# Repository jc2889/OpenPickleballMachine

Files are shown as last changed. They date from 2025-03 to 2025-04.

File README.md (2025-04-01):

# OpenPickleballMachine



# Open-Source Pickleball Throwing Machine

This project presents a cost-effective, open-source pickleball throwing machine designed to bridge the gap between affordability and advanced features. It provides adjustable speed, spin control, and reliable ball feeding, allowing players to practice and improve independently. The open-source design encourages community collaboration, customization, and innovation, empowering users to enhance the machine to suit their specific needs.

## Features

- **Adjustable Speed:** Customize the speed of ball throws for a range of practice scenarios.
- **Spin Control:** Fine-tune the spin for more realistic training.
- **Reliable Ball Feeding:** Ensures consistent ball delivery for continuous practice.
- **Open-Source:** Full access to the design and code, allowing for easy modification and improvements.
- **Easy Maintenance:** Built using off-the-shelf parts, making repairs and upgrades simple.

## Requirements
`BOM.XLSX` for materials sourcing.

# Tools required for assembly: 
3D Printer (That can print ABS/ASA), impact driver, power drill, soldering iron, crimpers, wire strippers, hot glue gun, hex driver set, jigsaw.

# 3D printing specs:
We suggest using either ASA/ABS or better as a filament. Suggested standard 3 wall, 25% gyroid/cubic infil, 0.6mm nozzle.
Rollers should be printed with 95A TPU.
### Our specs: ASA-CF for filament
### Our Printers: Voron 2.4 350, Prusa MK4s, Bambu lab X1C
***We suggest using cast polyurethane rubber rollers instead of 3d printed TPU rollers as they work significantly better**

## Installation

### 1. Hardware Setup
- Assemble the machine using off-the-shelf components, including motors, motor controllers, and the Raspberry Pi.
- Follow the wiring instructions provided in the `docs/instructions` folder to connect the components.

### 2. Software Setup
- Download balena etcher: https://etcher.balena.io/
- Using balena etcher, flash the .img file in `docs/firmware` folder to download the needed firmware or follow the instructions on how to create your own.

### Recommended Software:

MobaXterm for SSH access on Pi
https://mobaxterm.mobatek.net/ 

CAD Software for editing printed parts or for modifications
Fusion 3D is free and easily usable, other recommendations are FreeCAD, Sketchup or Blender.

Slicer for 3d printing; Prusaslicer
https://www.prusa3d.com/page/prusaslicer_424/

# Connect the Pi to Wifi:
1. Open the SD card on your computer (it should be mounted as the boot partition), or connect the Pi via ethernet and SSH into it.
2. In the root directory, create a file named `wpa_supplicant.conf` and add the following content:

   ```txt
   country=CA
   ctrl_interface=DIR=/var/run/wpa_supplicant GROUP=netdev
   update_config=1
   network={
       ssid="YOUR_SSID"
       psk="YOUR_PASSWORD"
   }
   
## For further documentation and instructions:

Visit `docs/assembly`

### Clone the repository:
  ```bash
  git clone https://github.com/jc2889/OpenPickleballMachine.git
  cd OpenPickleballMachine

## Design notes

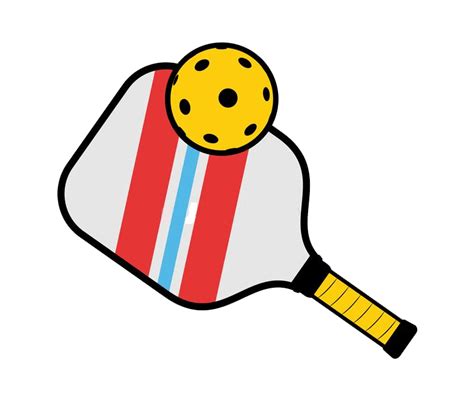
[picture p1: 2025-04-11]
docs/firmware/pickleball.jpeg

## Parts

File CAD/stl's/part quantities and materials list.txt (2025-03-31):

angle no slide.STL        - Qty: 2        - Material: ASA or PETG
angle slide.STL        - Qty: 2        - Material: ASA or PETG
ball disc.STL        - Qty: 1        - Material: ASA or PETG
ball_mover.STL        - Qty: 1        - Material: ASA or PETG
battery strap.STL        - Qty: 1        - Material: ASA or PETG
custom motor gear.STL         - Qty:2        - Material: ASA    (printed PETG example. please use the new STL file)
custom servo gear.STL        - Qty:1        - Material: ASA
custom wheel gear.STL        - Qty:2        - Material: ASA
electrical box.STL        - Qty:1        - Material: ASA or PETG
left mounting bracket.STL        - Qty:1        - Material: ASA or PETG
motor bracket.STL        - Qty:2        - Material: ASA
right mounting bracket.STL        - Qty:1        - Material: ASA or PETG
ring gear.STL        - Qty:1        - Material: ASA
roller frame.STL        - Qty:1        - Material: ASA
screen mount.STL        - Qty:1        - Material: ASA or PETG
TPU launcher wheel.STL        - Qty:1        - Material: TPU    (already printed)
tube.STL        - Qty:1        - Material: ASA or PETG

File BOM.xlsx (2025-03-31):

Date | Vendor | Item | Price (CAD) | GST (5%) | PST (7%) | Total (CAD) | Purchaced | link
2024-12-24 | Lee's Electronics | Sewable Neopixel WS2812 LED 5050 RGB x 2 | 8 | 0.4 | 0.56 | 8.96 | TRUE
2024-12-25 | Lee's Electronics | IEC Socket w/ Rocker Switch and Fuse Holder | 5.5 | 0.28 | 0.39 | 6.17 | TRUE
2024-12-26 | Lee's Electronics | Raspberry Pi 4 Model B, 4GB RAM | 97.5 | 4.88 | 6.83 | 109.21 | TRUE
2024-12-27 | Lee's Electronics | IEC Power Cord AWG18X3C 10FT | 6.8 | 0.34 | 0.48 | 7.62 | TRUE
2024-12-27 | Best Buy | Lexar 633X MicroSD 128GB | 13.99 | 0.7 | 0.98 | 15.67 | TRUE
 |  |  |  |  |  |  | FALSE
 |  |  |  |  |  |  | FALSE
2025- 02- 14 | home depot | battery | 34.77 | 1.7385 | 2.4339 | 38.9424 | TRUE | https://www.homedepot.ca/product/mighty-max-battery-ml9-12-12-volt-9-ah-f2-terminal-rechargeable-sla-agm-battery/1001859228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
 |  | battery charger | 20.13 | 1.0065 | 1.4091 | 22.5456 | FALSE | https://www.homedepot.ca/product/mighty-max-battery-12-volt-2-amp-sla-battery-charger-and-maintainer/1001860316
2025- 01-17 | Amazon | 2 driver motors | 47 | 2.35 | 3.29 | 52.64 | TRUE | https://a.co/d/i0Xx5XO
2025- 01-17 | Amazon | 2 dual driver escs | 30.22 | 1.511 | 2.1154 | 33.8464 | TRUE | https://www.amazon.ca/Channel-Controller-Semiconductor-Automotive-Electronics/dp/B07BKPV5Z7
2025- 02- 14 | aliexpress | 1 feeder motor (continuous servo) | 9.08 | 0.454 | 0.6356 | 10.1696 | TRUE | https://www.aliexpress.com/item/1005006777637870.html?pdp_ext_f=%7B%22order%22%3A%221%22%7D (https://www.aliexpress.com/item/1005008290985117.html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)
 |  | 2020 extrusion | 69.24 | 3.462 | 4.8468 | 77.5488 | FALSE | https://www.aliexpress.com/item/1005004263746376.html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
2025- 02- 14 | aliexpress | fasteners (M4 assorted length) | 10 | 0.5 | 0.7 | 11.2 | TRUE | https://www.aliexpress.com/item/1005004527586307.html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
2025- 02- 14 | aliexpress | m4 nuts |  | 0 | 0 | 0 | TRUE
 |  | 4 feeder wheels (maybe only 2, depending on budget) (could print TPU) | 21.98 | 1.099 | 1.5386 | 24.6176 | FALSE
2025- 01-17 | Amazon | voltage step down module | 12.59 | 0.6295 | 0.8813 | 14.1008 | TRUE | https://www.amazon.ca/LM2596S-Power-Module-DC-DC-Step-Down/dp/B0CXXP7RHP
2025- 01-18 | Home Depot | high current wires | 5.2 | 0.26 | 0.364 | 5.824 | TRUE | home depot
 |  | T Nuts (M4) | 5.93 | 0.2965 | 0.4151 | 6.6416 | FALSE | https://www.aliexpress.com/item/33023772052.html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
 |  | Couple Gallon Pale | 4.77 | 0.2385 | 0.3339 | 5.3424 | FALSE | https://www.homedepot.ca/product/the-home-depot-19l-orange-home-depot-logo-plastic-paint-bucket/1000143871
2025- 02- 14 | amazon | Bearings | 11.49 | 0.5745 | 0.8043 | 12.8688 | TRUE | https://www.amazon.ca/uxcell-4-inchx3-8-inchx1-Shielded-Bearings/dp/B0828JXX4N
2025- 02- 14 | aliexpress | servo driver board | 4.46 | 0.223 | 0.3122 | 4.9952 | TRUE | https://www.aliexpress.com/item/1005006298833960.html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
 |  | high torque servos x2 | 27.32 | 1.366 | 1.9124 | 30.5984 | FALSE | https://www.aliexpress.com/item/1005007792248497.html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
2025- 02- 14 | aliexpress | continuous servo | 9.08 | 0.454 | 0.6356 | 10.1696 | TRUE | https://www.aliexpress.com/item/1005006777637870.html?pdp_ext_f=%7B%22order%22%3A%221%22%7D (https://www.aliexpress.com/item/1005008290985117.html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)
 |  | cooling fan | 8.02 | 0.401 | 0.5614 | 8.9824 | FALSE | https://www.aliexpress.com/item/1005003140484906.html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
2025- 02-03 | Amazon | dupont wires | 8.99 | 0.4495 | 0.6293 | 10.0688 | TRUE | https://www.aliexpress.com/item/1005002599108827.html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
2025- 02-03 | Amazon | breadboard | 9.99 | 0.4995 | 0.6993 | 11.1888 | TRUE | https://www.aliexpress.com/item/1005004532352681.html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
 |  | 12 socket | 3.85 | 0.1925 | 0.2695 | 4.312 | FALSE | https://www.aliexpress.com/item/1005005827656117.html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
 |  | lipo | 89.97 | 4.4985 | 6.2979 | 100.7664 | FALSE
2025- 02-02 | Amazon | connectors | 10.99 | 0.5495 | 0.7693 | 12.3088 | TRUE
 |  | wood screws
 |  |  |  |  | Optional features | Total (CAD): | 657.3084
Spent in the display
Where | $ | Included in purchase
Lee's electronics | 131.94 | neopixels, pi, iec cord and socket
best buy | 15.67 | micro sd
amazon | 95.49 | 2 escs, 2 motors, 12v-5v step down modules
amazon | 10.07 | dupont wires
amazon | 25.74 | pi prototype board, pin header kit
home depot | 5.74 | 12 gauge wires
home depot | 38.94 | battery
aliexpress | 28.31 | continuous servos, servo controler, m4 hardware
amazon | 12.87 | bearings
home depot | 49.77 | 2 8ft boards, wood screws(1in and 3in), hinges, bucket, axle bolts + nuts, m4 washers
Home Depot | 20.68 | Wagos, wire, spade connectors.
amazon | 48.99 | screen
total spent | 484.21
remaining | 15.79

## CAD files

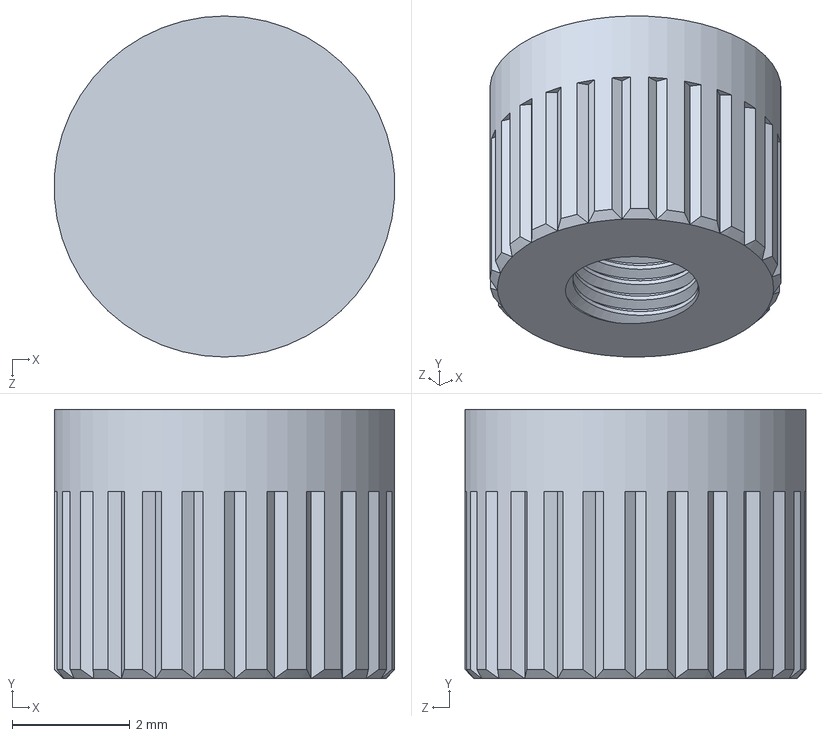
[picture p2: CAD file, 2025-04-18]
CAD/SOLIDWORKS/Shaft.SLDPRT
5.79 x 4.58 x 5.80 mm

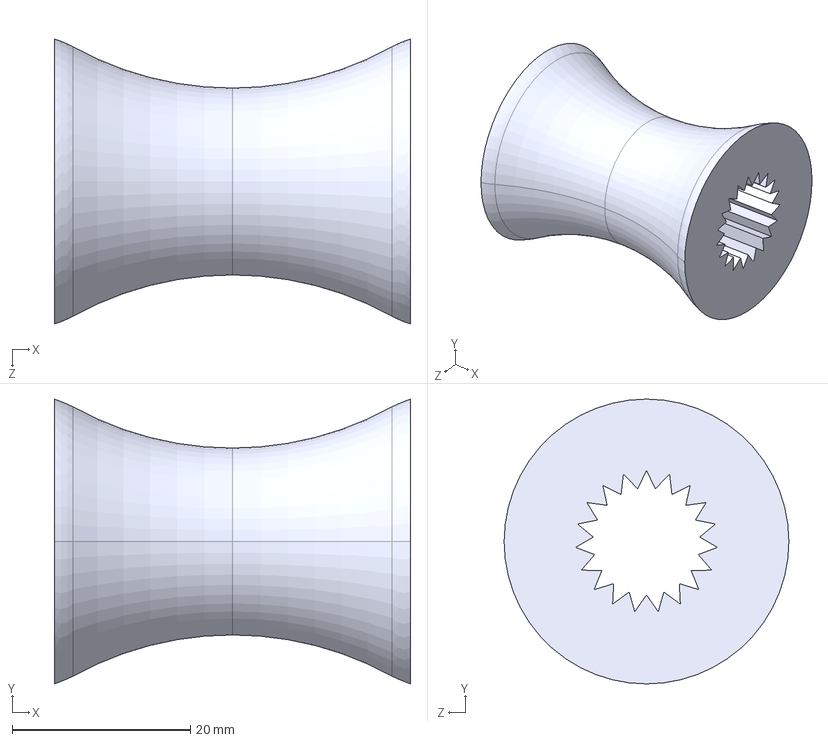
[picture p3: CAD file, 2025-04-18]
CAD/STEP files/TPU launcher wheel undersize.STEP
40.0 x 32.0 x 32.0 mm

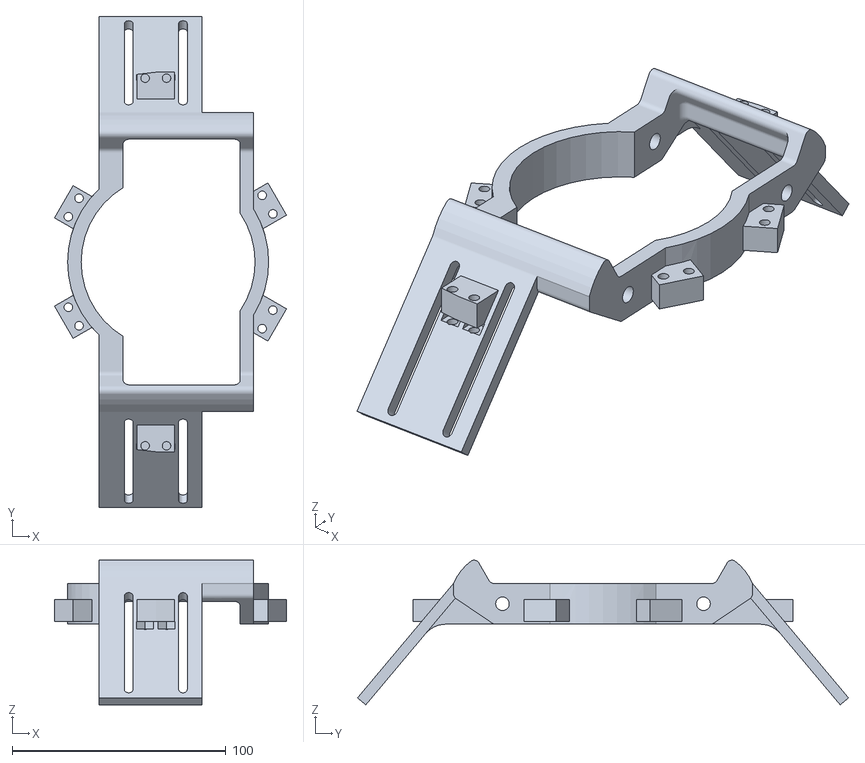
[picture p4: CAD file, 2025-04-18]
CAD/stl's/roller frame.STL
108.5 x 229.5 x 67.6

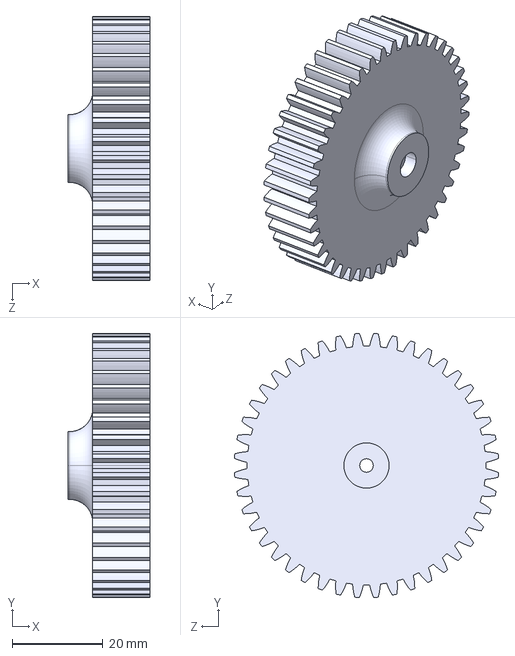
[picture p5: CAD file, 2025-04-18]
CAD/STEP files/custom servo gear.STEP
18.2 x 58.3 x 58.3 mm

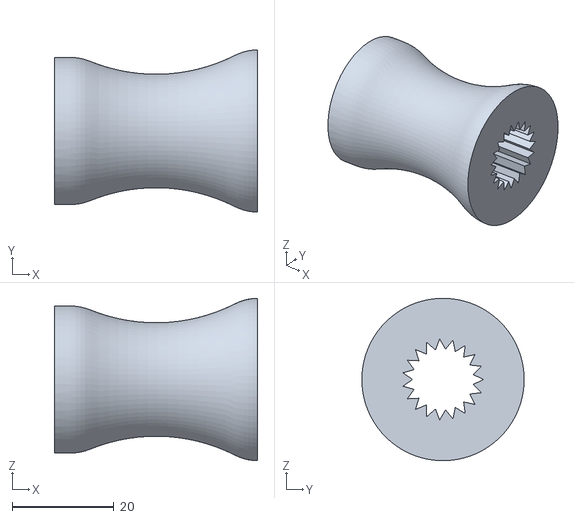
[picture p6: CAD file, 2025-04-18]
CAD/stl's/TPU launcher wheel 2%.STL
40.0 x 32.0 x 32.0

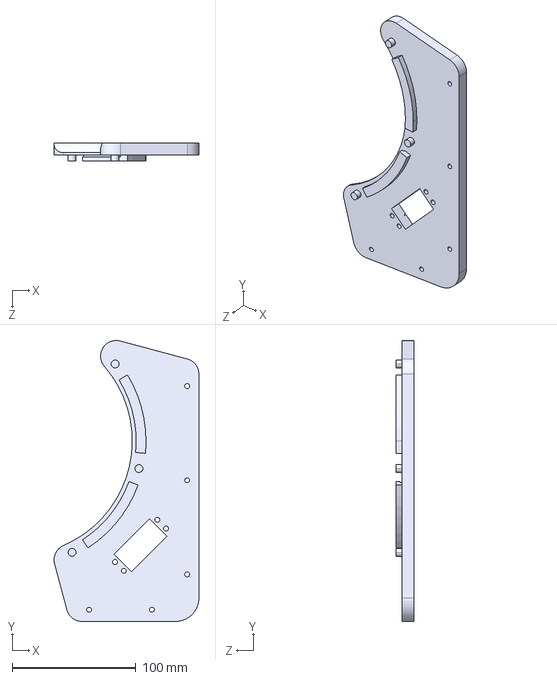
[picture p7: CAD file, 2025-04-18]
CAD/STEP files/right mounting bracket.STEP
117.2 x 227.4 x 14.3 mm

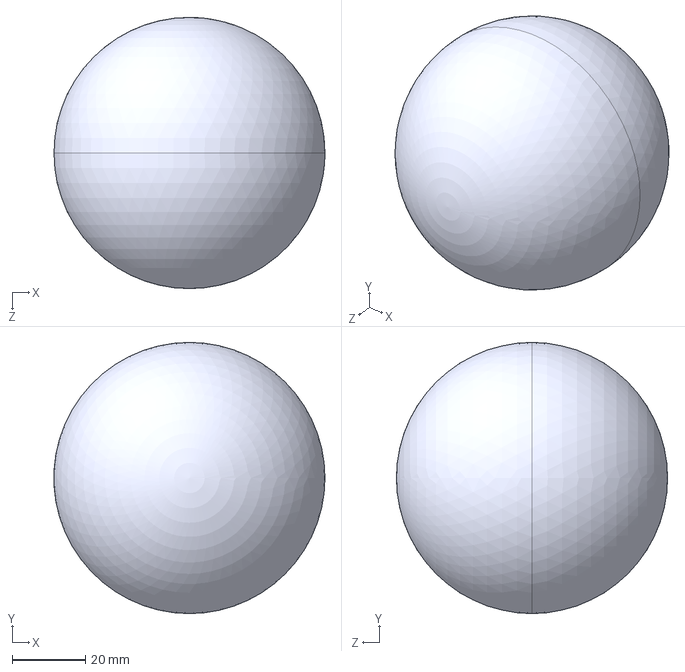
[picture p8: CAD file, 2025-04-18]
CAD/STEP files/pickleball.STEP
73.9 x 74.0 x 74.0 mm

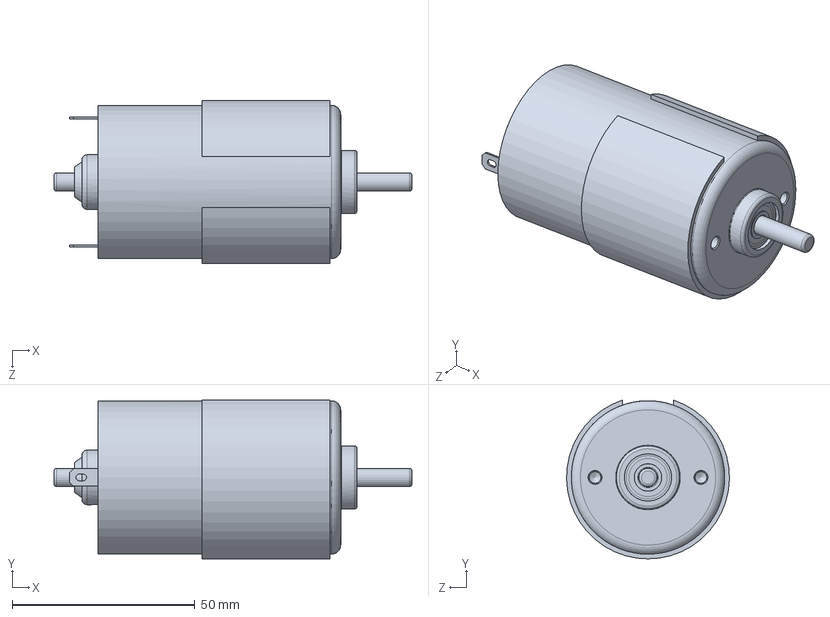
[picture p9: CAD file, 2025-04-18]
CAD/SOLIDWORKS/Motor - RS-775 simplified.SLDPRT
98.0 x 43.5 x 44.6 mm

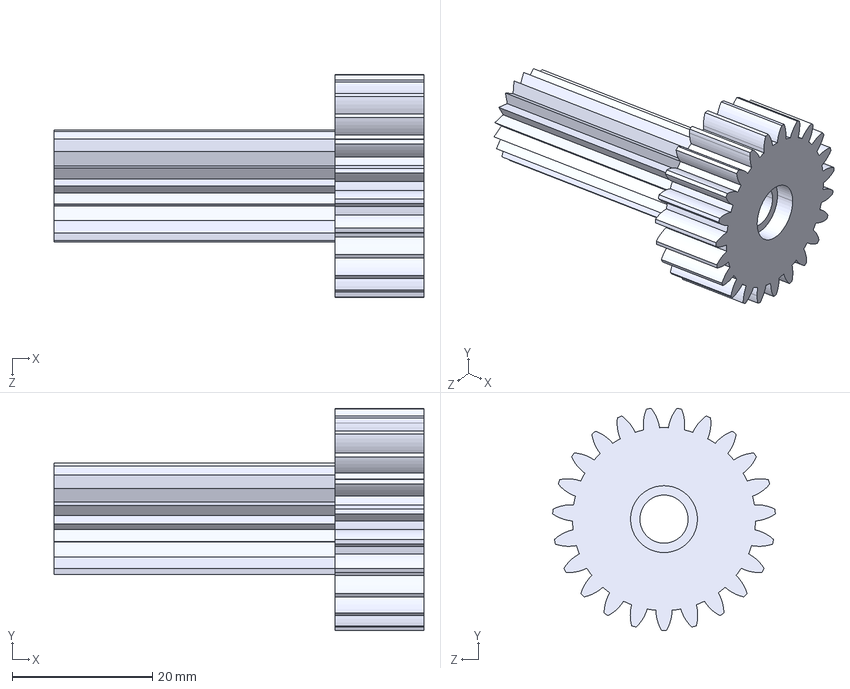
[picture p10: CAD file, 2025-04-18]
CAD/STEP files/custom wheel gear.STEP
52.7 x 31.6 x 31.7 mm

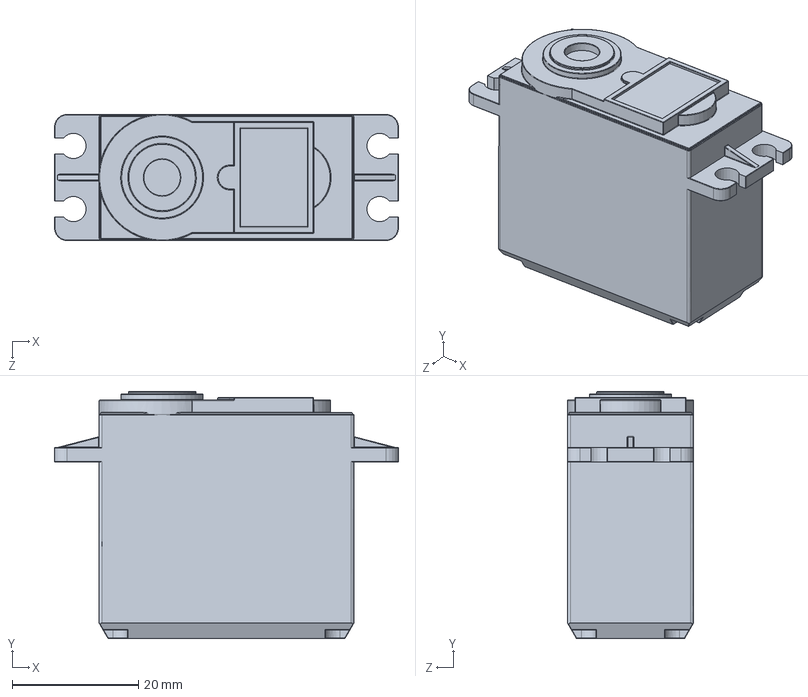
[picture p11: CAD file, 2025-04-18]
CAD/SOLIDWORKS/MG995.SLDPRT
54.5 x 39.2 x 20.0 mm

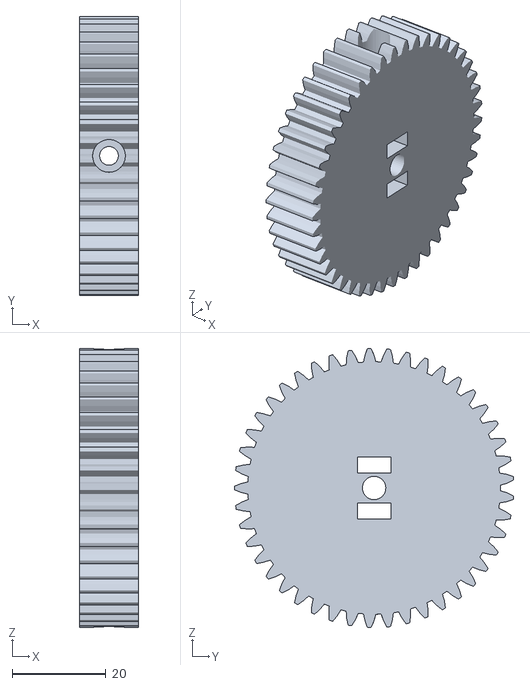
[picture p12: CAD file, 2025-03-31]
CAD/stl's/custom motor gear.STL
12.7 x 59.6 x 59.7

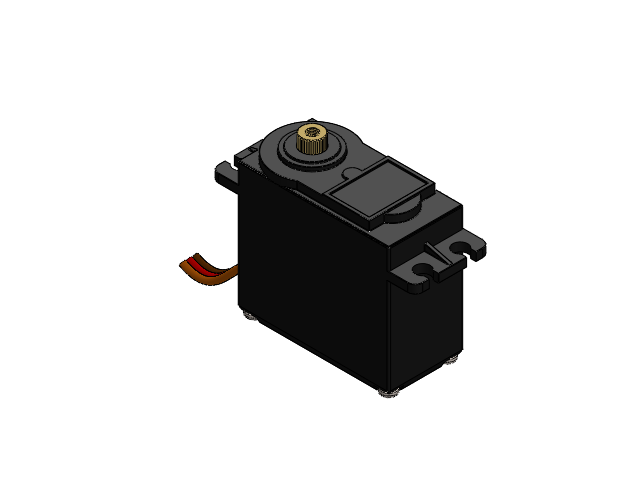
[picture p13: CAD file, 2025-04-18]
CAD/SOLIDWORKS/MG995 Assembly.SLDASM
MG995
Shaft
Wire Boot
Wires
pan head tapping screw_am x 4

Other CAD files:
CAD/SOLIDWORKS/Wire Boot.SLDPRT
CAD/stl's/TPU launcher wheel.STL
CAD/SOLIDWORKS/Wires.SLDPRT
CAD/stl's/TPU launcher wheel 1%.STL
CAD/stl's/TPU launcher wheel 5%.STL
CAD/STEP files/left mounting bracket.STEP
CAD/SOLIDWORKS/2x3 wood.SLDPRT
CAD/SOLIDWORKS/57155K375_Stainless Steel Ball Bearing.SLDPRT
CAD/SOLIDWORKS/TPU launcher wheel.SLDPRT
CAD/SOLIDWORKS/angle no slide.SLDPRT
CAD/SOLIDWORKS/angle slide.SLDPRT
CAD/SOLIDWORKS/ball disc.SLDPRT
CAD/SOLIDWORKS/ball_mover.SLDPRT
CAD/SOLIDWORKS/battery strap.SLDPRT
CAD/SOLIDWORKS/battery.SLDPRT
CAD/SOLIDWORKS/bucket.SLDPRT
CAD/SOLIDWORKS/custom motor gear.SLDPRT
CAD/SOLIDWORKS/custom servo gear.SLDPRT
CAD/SOLIDWORKS/custom wheel gear.SLDPRT
CAD/SOLIDWORKS/electrical box.SLDPRT
CAD/SOLIDWORKS/feed.SLDASM
CAD/SOLIDWORKS/left mounting bracket.SLDPRT
CAD/SOLIDWORKS/motor bracket.SLDPRT
CAD/SOLIDWORKS/pickleball.SLDPRT
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

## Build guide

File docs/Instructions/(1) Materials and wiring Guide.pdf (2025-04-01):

Appendix B: Open-Source and Assembly Instructions

B.1 Materials List

Below is a comprehensive list of all components required to replicate the pickleball throwing machine. All parts were selected based on affordability, availability, and DIY-friendliness. Suggested quantities and models are included. Links to product pages should be added by the user.

Electronics & Control

- 1× Raspberry Pi 4 Model B (2GB or higher)
Used for system control and user interface
[Link: https://www.raspberrypi.com/products/raspberry-pi-4-model-b/ ]
- 1× Micro SD Card (16GB or higher)
Used to boot and store the Raspberry Pi OS and project files
[Link:
https://www.bestbuy.ca/en-ca/product/sandisk-ultra-32gb-100mb-s-micro-sd-card-sdsquns-032g/13695879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]
- 1× Touchscreen Display (HDMI + USB input)
Used for real-time user control and configuration
[Link: https://www.amazon.ca/dp/B0CRRB1GFN?ref=ppx_yo2ov_dt_b_fed_asin_title]
- 1× LM2596S-5 Step-Down Voltage Regulator (12V to 5V)
Powers the Raspberry Pi from the main battery source
[Link:
https://www.amazon.ca/LM2596S-Power-Module-DC-DC-Step-Down/dp/B0CXXP7RHP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

UEfcUG44k5tJmPM3_J5_e1sBA_XIdUGrHoy6O_dAi2qjwUb-T0oHOcF3PnMQ1Fbg6r xxjV_53fNjoton0Xw2flCZ0HFcfvkkV4ATEcKNaDElkPZLy1HC2ggzfiFFqW-Wuaou6i VbMOvFhtdLrhzn24Iu5p8BXH8brrUAQH5xhcgiR5VlnAJRgs0amjl5_XgnRwlNp2qFN HwF-DhspwvmSVJvMDXM-oN_leD7jP86jVoSHVq1IfZ5wOAe8mCK0iO3JjLW1x_53 9MTUuLQy3wqc1NwYH2haOptJFfr_3Fhiy6Fi46hQq2HwQak2tl5K6-F_tm_RPEVEFzc ZeDDBXCPSmZ0Qq0DqK-jIWgWqdBzE7lKTOcrpseL89hBiCYbnfYnxfhwVLos2N_u psiK6GmBS8fbpXS2R-uT8C3D.5NMLD2pXluSVnKJdG1vdfo3LKvzGY6NUs-Yc04AmDs&dib_tag=se&keywords=12v+to+5v&qid=1737091439&sprefix=12v+to+5v%2Cap s%2C176&sr=8-13]

- 1× PCA9685 16-Channel PWM Servo Driver
Controls both continuous rotation servos
[Link:
https://www.aliexpress.com/item/1005006298833960.html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 2.99%21%21%2122.20%2114.88%21%402101ea8c17371818965312061e904d%211200 0037529842018%21sea%21CA%210%21ABX&curPageLogUid=4X131uRG9vee&utpa ram-url=scene%3Asearch%7Cquery_from%3A]
- 1× 12V 9Ah Sealed Lead-Acid (SLA) Battery (Mighty Max ML9-12 or equivalent) Main power source for motors and electronics
[Link:
https://www.homedepot.ca/product/mighty-max-battery-ml9-12-12-volt-9-ah-f2-terminal-rechargeable-sla-agm-battery/1001859228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]

Motors & Actuation

- 2× 775 DC Motors (12V, 0.32A, ~13000 RPM)
Used to drive the launching wheels
[Link:
https://www.amazon.ca/dp/B0C1CPVVTF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]
- 2× Continuous Rotation Servo Motors (DS04-NFC or equivalent)
Used for the feeding and launch angle adjustment mechanisms
[Link:
https://www.aliexpress.com/item/1005008290985117.html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 17.99%21%21%215.42%215.42%21%402101d9ee17371786323311474e7289%2112000 044500754039%21sea%21CA%210%21ABX&curPageLogUid=Bqh9kpQDENj1&utpar am-url=scene%3Asearch%7Cquery_from%3A]
- 2× Single-Channel H-Bridge Motor Driver Boards (LM2936 or equivalent)
Drives each DC motor independently
[Link:
https://www.amazon.ca/Channel-Controller-Semiconductor-Automotive-Electronics/dp/B07BKPV5Z7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 nd_I_gst6TK-PtAlmoOAyVeUgy72iNZ8jGLESIwvJhgZofWLVTq-59tQ.NiJSd1uO-fCIn A9ndMZXKSzmSezdCYtIfWHHJfYA8nI&dib_tag=se&keywords=Cytron&qid=173708 9191&sprefix=cytron%2Caps%2C133&sr=8-9]

Connectors & Wiring

- 1× Pi Prototype Board or Breadboard Kit
Optional, for initial testing or soldered connections
[Link: https://52pi.com/products/52pi-prototype-hat-breadboard-for-raspberry-pi]
- 1× IEC Power Connector and Socket
Used for battery charging or external supply integration
[Link:
https://leeselectronic.com/en/product/21069-rocker-switch-w-iec-socket-fuse-holder-scre w.html]
- Assorted Wires (Dupont jumper wires, 12-gauge power wire)
Used for general wiring and power distribution
[Link:
https://www.aliexpress.com/item/1005002599108827.html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 1.51%21%21%211.53%211.03%21%402101c72a17371787415886971e5288%21120000 21331960075%21sea%21CA%210%21ABX&curPageLogUid=5epYVaPxuz0v&utpara m-url=scene%3Asearch%7Cquery_from%3A]
- Wago Connectors / Spade Connectors / Crimp Connectors
Used for secure and modular electrical connections
[Link:
https://www.wago.com/us/wire-splicing-connectors/compact-splicing-connector/p/221-41 5

https://www.amazon.ca/Feggizuli-Connectors-Connector-Terminals-Electrical/dp/B0B4H54KPS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

Y373MlpljQ9zPu-LacliQaF39fZeV0qy6bNfHnF6yWLbiUenfBHIx9XyQ1AL73CVxRG nCx4ViPi1PsrHIaxYomVC1huoSW3w68LiIhB92PaaS9dyNqZ-T6hOQ5OmxSmn7ZPFx wzBjch5a2xmrfxqoQRawVI_1fXR0JRG6zMQYGY_Moy_Bo5onXIK2jXxIToPGEzzyR JmuDMHwP61LeLEHjvlTD2ONXqf7h0f6rD89CmdRs_y0MLoSyWjPZOsF7K5JTbLR bOq5-R1i2peszIHY4XDFRbTHvxA89KO.FW5X3_TQc9tTwtC4Ou_upmIkmzB4S1Yf9 0mqSlbb-wU&dib_tag=se&keywords=crimp%2Bconnectors&qid=1742840991&sprefix =crimp%2Bconn%2Caps%2C166&sr=8-5&th=1

]

Mechanical Components

- Ball Bearings
Used in rotating or tensioned mechanisms (e.g., launcher wheel support)
[Link:
https://www.amazon.ca/uxcell-4-inchx3-8-inchx1-Shielded-Bearings/dp/B0828JXX4N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 JA0odIiIrXa23jwhvvUkC6XhbRQbEkHLWW4aVSqbcJ-1Y5R0fIdq7NMTvEclMCSJS DTkXp-NO7ihhKi7ocJxLhDykAkWBJu8sXgKtQieVuz6eOibPwWEZuAdzsjlqHSZOhs 8nxDZWPw3O_nTudCbqRS32JfDAZ3VgffWXdLzzN9frLyi1UbHw7j3oU07YROJ6zka QrvMHsMKraH73GqhuZsKnmoGvA1HQ0HNL_d-VbIYoonpJrk5fKrcpjC6f-PYqBdqU 2l26MgjidUoKc_FDIrM0csy.SX76jApIdP0uKtFNR7KGz4ll7OHpeIGds-Eaol1bF00&di b_tag=se&keywords=r168+bearings&qid=1738465099&sprefix=r168+bearings%2Caps %2C156&sr=8-5]
- M4 Hardware (Nuts, Bolts, Washers, Axle Bolts)
Used for mounting and assembly of 3D printed and mechanical components [Link:

https://www.amazon.ca/uxcell-4-inchx3-8-inchx1-Shielded-Bearings/dp/B0828JXX4N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 JA0odIiIrXa23jwhvvUkC6XhbRQbEkHLWW4aVSqbcJ-1Y5R0fIdq7NMTvEclMCSJS DTkXp-NO7ihhKi7ocJxLhDykAkWBJu8sXgKtQieVuz6eOibPwWEZuAdzsjlqHSZOhs 8nxDZWPw3O_nTudCbqRS32JfDAZ3VgffWXdLzzN9frLyi1UbHw7j3oU07YROJ6zka QrvMHsMKraH73GqhuZsKnmoGvA1HQ0HNL_d-VbIYoonpJrk5fKrcpjC6f-PYqBdqU 2l26MgjidUoKc_FDIrM0csy.SX76jApIdP0uKtFNR7KGz4ll7OHpeIGds-Eaol1bF00&di b_tag=se&keywords=r168+bearings&qid=1738465099&sprefix=r168+bearings%2Caps %2C156&sr=8-5]

3D Printing Materials

- ASA Filament
Used for UV-resistant structural parts (e.g., housing, brackets, gear mounts)
[Link:
https://www.amazon.ca/OVERTURE-Filament-Printing-Functional-Dimensional/dp/B0CPXJ5RT5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 nYhMUHoh42gcPcDPtNrK8LWNEGwSeBvwujehLXBeuuoIzAaOHktBm6yJQtjcNTSo ic8xHXADM2VMjD_qMwBSrLBBi7zRUsGRB-Tz6GOYY41B9lzSnhXQRBD3hfNbm o4QpjYdYghtJ9GUcDclWFzBKRjnOenCm96hHoBPCW8JczFjgbiZQzmIzm3-wgDIRo nozKl2Jz4l_1L1LeDvdSP9dXaxpA5lgmM5mpZWMabjfJh5DLj_j8nRhidufNIL1fjajimS lIMT5cLNcJs--xILtIuNxDWstNrf0uH5T.2du9scbxr5CsAZkDjtP-O_YdQ9Zhw9_OqF90 2w9sM5c&dib_tag=se&keywords=asa+filament&qid=1742841067&sprefix=ASA+%2C aps%2C149&sr=8-5]

- TPU Filament
Used for the launcher wheels for improved grip and durability
[Link:
https://www.amazon.ca/Overture-Filament-Flexible-Consumables-Dimensional/dp/B0841CKM6F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 Hvf0JEu7HP7U2q5govOFFEiop0jMCJF7f5X0Vb3NjRivQOP9Z6Z5bPU2YcbK7JQZm HZmbNwMq_mOobjK48ZvcvwtWD6ROXQ-zXxAtpW0fYZYjGwAcfO5hKnFCKZBS Oi2-kDT7fdJsfFm0CiepwvwyTkA7qpKPfOFI6m9vUVBJcTGlsLISVCLdDRup9SCTIpI 8932ixUVRU-bW_Q.qmH6Ia461wtSs05FTvUrReXaVvYWkNlcH1Hd2mCed98&dib_t ag=se&keywords=tpu+filament&qid=1742841080&sprefix=tpu+filament%2Caps%2C17 7&sr=8-5]

Frame Materials

- 2× 8-ft Wooden Boards
Used for the base and support structure
[Link:
https://www.homedepot.com/p/2-in-x-3-in-x-8-ft-2-Select-Grade-Dimensional-Lumber-845000/100038668]
- Wood Screws (1” and 3”)
General assembly of frame and component mounting
[Link:
https://www.homedepot.ca/product/kreg-tool-company--8-1-1-4-inch-square-maxi-loc-head-coarse-zinc-plated-steel-pocket-hole-screw-100-pack-/1000711142]
- Hinges, Bucket, and Additional Support Brackets (as required)
Used for ball loading and launch positioning mechanisms

[Link:
https://www.homedepot.ca/product/the-home-depot-19l-orange-home-depot-logo-plasticpaint-bucket/1000143871

https://www.homedepot.ca/product/richelieu--2-pack-non-mortise-bifold-inset-hinge-forframed-cabinet-matte-black/1001066169]

B.2 Electrical Connections

This section provides an overview of the electrical wiring required to operate the pickleball throwing machine. The system is powered by a 12V sealed lead-acid battery, stepped down via a voltage regulator to supply safe and consistent power to the Raspberry Pi 4B, motors, and servo controller.

A complete circuit schematic is provided below for reference, along with supporting images of the prototype wiring.

B.2.1 System Overview

- Power Source:
A 12V 9Ah SLA battery powers the entire system. The Raspberry Pi is powered via a LM2596 step-down converter that outputs 5V.
- Motor Drivers:
Two DC motors are controlled using single-channel H-bridge drivers (LM2936). Each motor is wired to a separate GPIO pair on the Raspberry Pi for directional control.
- Servo Controller:
A PCA9685 PWM driver board is connected via I2C to control two continuous rotation servo motors (for feeding and launch angle adjustment).
- Display Power:
The touchscreen display connects via micro HDMI and USB, and is powered via the Raspberry Pi. (In earlier iterations, powering the display directly caused instability, which was resolved by powering the Pi through the LM2596 converter.)

B.2.2 Circuit Schematic

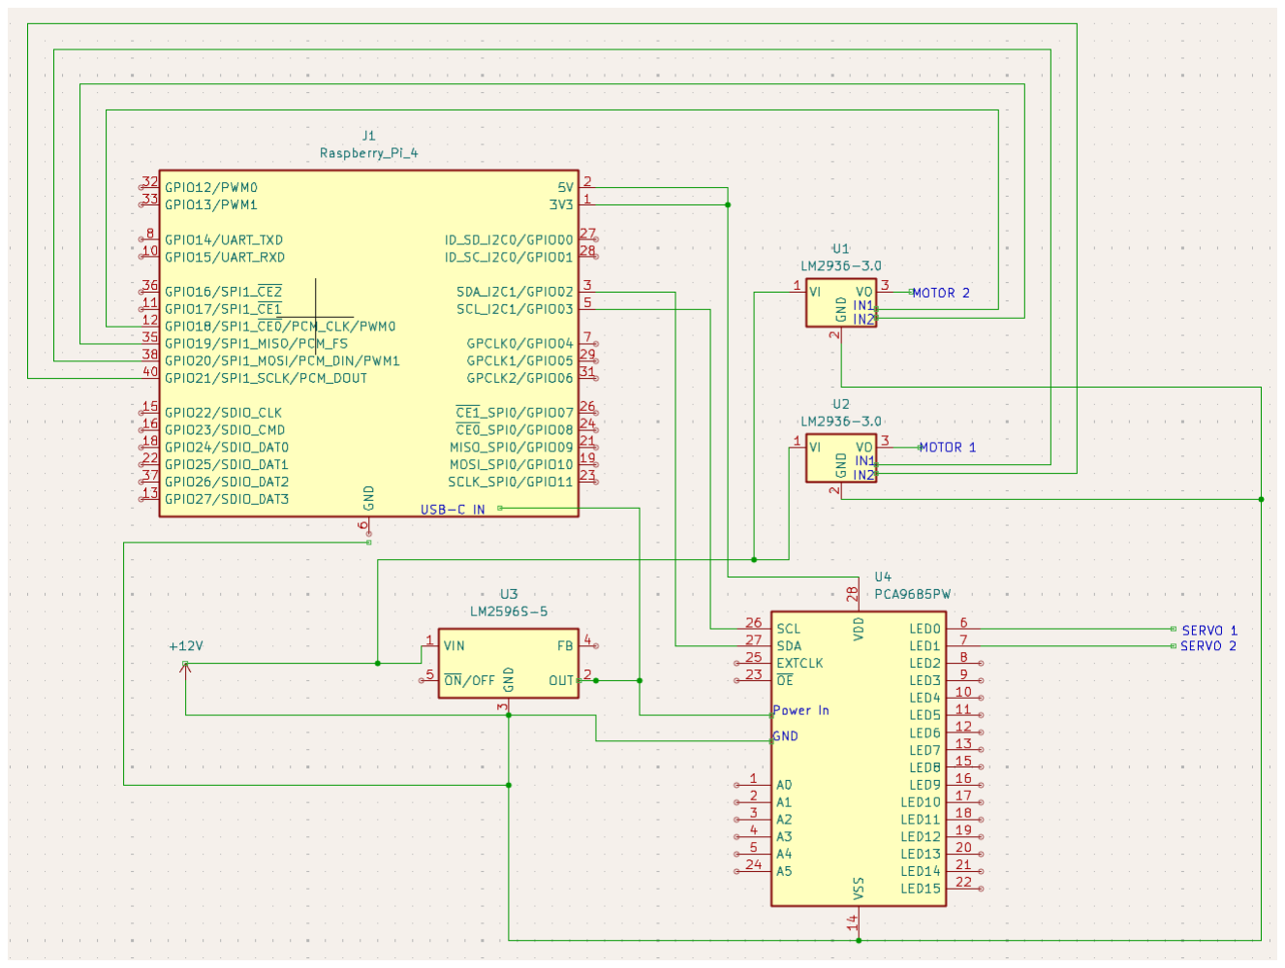
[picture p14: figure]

Figure B.1 – Full Circuit Schematic for Pickleball Throwing Machine

B.2.3 Wiring Images

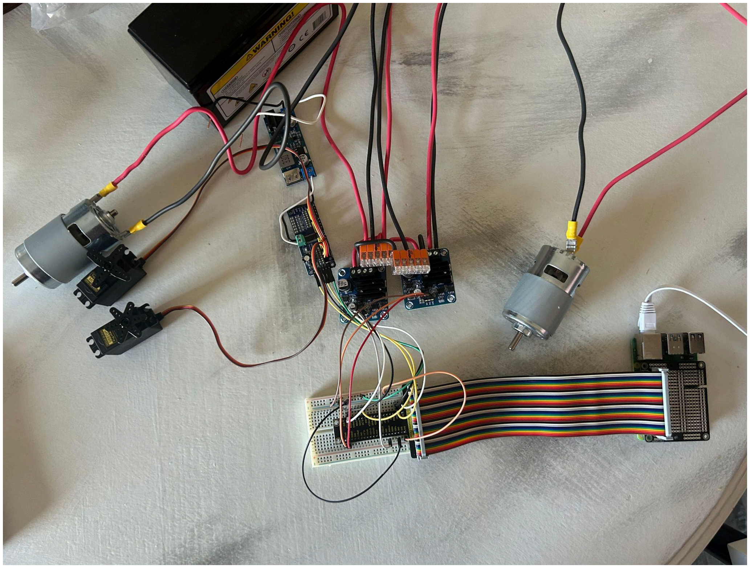
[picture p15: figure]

Figure B.2 – Assembled Wiring Example

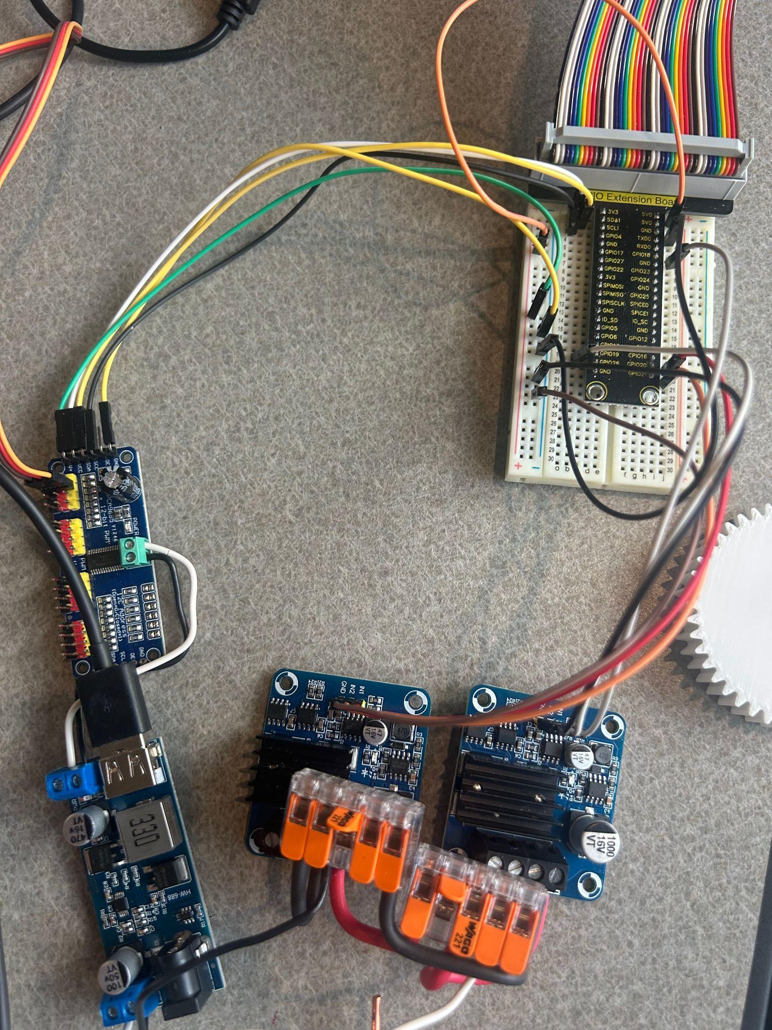
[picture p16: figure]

Figure B.3 – Close-up of Motor Driver Wiring and Power Distribution

B.2.4 GPIO and I2C Pin Mapping (Raspberry Pi)

Function | Raspberry Pi Pin | Connection
Servo I2C – SDA | GPIO 2 (Pin 3) | PCA9685 SDA
Servo I2C – SCL | GPIO 3 (Pin 5) | PCA9685 SCL
Motor 1 IN1 / IN2 | GPIO 18 / GPIO 19 | LM2936 (Motor 1)
Motor 2 IN1 / IN2 | GPIO 20 / GPIO 21 | LM2936 (Motor 2)
Power Output | 5V / GND | Servo Driver, Display, Pi
USB-C Power Input | – | From LM2596 5V Output

B.2.5 Notes and Tips

- Power Sequencing: Always connect the battery last, after confirming all wiring.
- Wire Gauge: Use at least 12 AWG for battery-to-motor and regulator connections.
- Test Step-by-Step: First confirm power to Pi and screen, then test motors/servos individually using sample scripts.
- Optional: Use inline fuses or Wago-style connectors to improve electrical safety and modularity.

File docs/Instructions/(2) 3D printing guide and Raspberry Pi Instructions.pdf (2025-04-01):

## B.3 3D Printed Parts

This project includes several custom 3D printed components that form the mechanical foundation of the pickleball throwing machine, including the launcher, gear train, servo mechanisms, and electronic mounting structures.

All STL files, updated part revisions, and print settings are available in the project’s GitHub repository:
(https://github.com/jc2889/OpenPickleballMachine)

Below is a complete list of parts to be printed, including recommended quantities and materials.

B.3.1 3D Printed Part List

File Name | Quantit y | Material | Notes
angle no slide.STL | 2 | ASA or PETG | Support frame component
angle slide.STL | 2 | ASA or PETG | Movable guide
ball disc.STL | 1 | ASA or PETG | Feeding mechanism
ball_mover.STL | 1 | ASA or PETG | Rotates ball into firing chamber
battery strap.STL | 1 | ASA or PETG | Battery securing bracket

custom motor gear.STL | 2 | ASA | Printed PETG in early prototype
custom servo gear.STL | 1 | ASA | Drives ring gear
custom wheel gear.STL | 2 | ASA | Printed PETG in early prototype
electrical box.STL | 1 | ASA or PETG | Houses Raspberry Pi and wiring
left mounting bracket.STL | 1 | ASA or PETG | Structural support
motor bracket.STL | 2 | ASA | Holds 775 DC motors
right mounting bracket.STL | 1 | ASA or PETG | Structural support
ring gear.STL | 1 | ASA | Controls launch angle via servo gear
roller frame.STL | 1 | ASA | Frame for launching wheel assembly
screen mount.STL | 1 | ASA or PETG | Mounts touchscreen to frame
TPU launcher wheel.STL | 1 | TPU | Pre-printed; provides grip for launch

tube.STL | 1 | ASA | or
| | PETG

Ball guide / firing tube

B.3.2 Material Notes

- ASA is recommended for parts exposed to sunlight or mechanical load, due to its UV resistance and rigidity.
- PETG is acceptable for internal or low-load components.
- TPU is used for the launcher wheel due to its flexibility and grip.

Please refer to the GitHub documentation for specific print orientation, infill settings, and support recommendations.

B.4 Raspberry Pi Setup (with Software Overview)

B.4.1 Flashing the SD Card

Before setting up the Raspberry Pi, flash the Raspberry Pi OS onto an SD card. For detailed instructions, please refer to the following guide:

- Flashing | Guide: | Official | Raspberry | Pi | Imager | Documentation
(https://www.raspberrypi.com/documentation/computers/getting-started.html#installing-t he-operating-system)

B.4.2 Configuring I2C and Enabling Interfaces

After flashing and booting up your Raspberry Pi, follow these steps to enable I2C communication:

1. Run Raspberry Pi Configuration:
Open a terminal and enter:

### sudo raspi-config

2. Enable I2C:
- Navigate to Interface Options → I2C → Enable.
- Exit the configuration tool and reboot if prompted.
3. Verify I2C is Enabled:
After reboot, open the file /boot/config.txt by running:

### sudo nano /boot/config.txt

Look for a line like:

### dtparam=i2c_arm=on

If the line is commented out (i.e., starts with a #), remove the #, save the file, and reboot.

4. Check Wiring:
- On a standard Raspberry Pi, SDA is physical pin 3 (GPIO 2) and SCL is physical pin 5 (GPIO 3).
- Ensure your PCA9685 module is wired correctly:

■ SDA → Pi GPIO 2 (Pin 3)

■ SCL → Pi GPIO 3 (Pin 5)

■ Also verify that the 3.3V and GND pins are correctly connected.

5. Test I2C Communication:
Install the i2c-tools if not already installed:

### sudo apt-get install -y i2c-tools

Then run:

### i2cdetect -y 1

This should display the connected I2C devices, including your PCA9685.

B.4.3 Installing Required Libraries

Install the following Python libraries, which are necessary for motor control and UI functionality:

1. RPI.GPIO:

### sudo apt-get install python3-rpi.gpio

2. Adafruit CircuitPython ServoKit:

### pip3 install adafruit-circuitpython-servokit

3. Kivy (for UI development):

### sudo apt-get install python3-kivy

Alternatively, follow the official Kivy installation instructions if you need a specific version: https://kivy.org/doc/stable/installation/installation.html

B.4.4 Deploying the UI Script

1. Download the UI File:
Ensure that the UI.py file (which contains your touchscreen interface code) is

downloaded and placed in a known directory (e.g., /home/pi/).

2. Testing the UI:
Run the UI manually to confirm it operates correctly:

### python3 /home/pi/UI.py

B.4.5 Creating an Autostart .desktop File

To automatically launch the UI on startup:

1. Create a .desktop File:
Open a text editor and paste the following content (adjust paths as necessary):

### [Desktop Entry]

### Version=1.0

### Type=Application

### Name=Pickleball App

### Comment=Launch the Pickleball Control Panel

### Exec=/usr/bin/python3 /home/pi/UI.py

### Icon=application-default-icon

### Terminal=false

Categories=Utility;

2. Save the File:
Save it as PickleballApp.desktop in the Desktop directory (e.g.,
/home/pi/Desktop/).
3. Make the .desktop File Executable:
Open a terminal and run:

### chmod +x /home/pi/Desktop/PickleballApp.desktop

After these steps, on reboot the Raspberry Pi will automatically launch your UI application.

B.4.6 Troubleshooting

- Package Conflicts or Errors:
When installing libraries like kivy or adafruit-circuitpython-servokit,

you may encounter package conflicts or missing dependencies. In some cases, you may need to uninstall or reinstall Python packages, or use pip3 with

--break-system-packages to override system-level restrictions:

### pip3 install kivy --break-system-packages

- Kivy UI Not Launching:
If the touchscreen UI (UI.py) doesn't launch:
- Double-check that the file is executable.
- Make sure all required Python libraries are installed.
- Try running it manually in terminal with:

### ■ python3 /home/pi/UI.py

- I2C Devices Not Detected:
If i2cdetect -y 1 shows no devices:
- Ensure SDA and SCL are connected to GPIO 2 and GPIO 3 respectively.
- Re-check that I2C is enabled in raspi-config.
- Confirm that 3.3V and GND are properly connected.
- Display Not Powering On:
If the display causes power issues or the Pi doesn't boot:
- Make sure the Raspberry Pi is powered through the step-down converter rather than the display drawing directly from USB.

- Confirm that the battery voltage is stable and sufficient.
- General Debugging Tips:
- Reboot the Pi after major changes.
- Use htop to check for CPU load if the system freezes.
- Use dmesg or journalctl -xe to view system logs for hardware-related

errors.

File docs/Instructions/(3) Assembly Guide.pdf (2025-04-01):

B.6 Assembly Instructions

This section outlines the general steps for assembling the pickleball throwing machine once all components have been printed, wired, and prepared.

Note: For visual reference, please refer to the CAD models and exploded views in
the GitHub repository (https://github.com/jc2889/OpenPickleballMachine).
Step 1: Mount Motors to Motor Brackets
- Insert each 775 DC motor into the motor bracket.STL.
- Secure the motors using M4 bolts and nuts.
- Ensure the motor shafts are aligned and facing the launching direction.
Step 2: Assemble the Launcher Wheel System
- Attach TPU launcher wheel.STL to each motor shaft.
- Align the wheels within the roller frame.STL to ensure the pickleball fits snugly between them.
- Mount the entire roller frame to the wooden base using screws or bolts.
Step 3: Mount Servo and Ring Gear System

- Attach the continuous rotation servo to its designated bracket.
- Connect the custom servo gear.STL to the servo shaft.
- Engage the servo gear with the ring gear.STL to enable rotation of the launcher assembly for directional control.
- Ensure smooth rotation and secure mounting to prevent gear skipping.
Step 4: Install Feeding Mechanism
- Mount the ball disc.STL and ball_mover.STL to guide balls into the launcher wheels.
- Attach the second servo to drive the feeding disc using custom motor gear.STL.
- Position the tube.STL to direct balls from the feeder into the launcher gap.
Step 5: Mount Control Electronics
- Secure the electrical box.STL to the frame or underside of the launcher.
- Mount the Raspberry Pi, PCA9685, and motor drivers inside the electrical box using M2 screws or double-sided tape.
- Route wires carefully and use Wago or spade connectors for clean and safe connections.

Step 6: Secure Battery and Display
- Mount the battery to the base using the battery strap.STL or zip ties.
- Mount the touchscreen display using the screen mount.STL and orient it for easy user access.
- Connect the display via HDMI and USB to the Raspberry Pi.
Step 7: Final Assembly and Testing
- Perform a final wiring check. Ensure:
- No loose connections
- Battery polarity is correct
- Step-down voltage is properly regulated
- Power on the system and test each component individually:
- Motors
- Servos
- UI responsiveness
- Once verified, test a full launch cycle with a pickleball.

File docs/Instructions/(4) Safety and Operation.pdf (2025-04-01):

## B.7 Safety and Operating Instructions

This section provides important safety guidance and basic operating procedures to ensure safe and effective use of the pickleball throwing machine.

B.7.1 Safety Instructions

General Safety

- Only operate the machine on a flat, stable surface.
- Keep hands, tools, and loose clothing away from all moving parts during operation.
- Ensure the launch zone is clear before powering on the motors.
- Always supervise the machine while powered on.

Electrical Safety

- Double-check all wiring connections before connecting the battery.
- Use proper wire gauge for power connections (minimum 12 AWG for motor and battery circuits).
- Never short the battery terminals.
- Power off the system before performing any maintenance or component swaps.

Battery Handling

- Use a sealed lead-acid (SLA) battery charger only.
- Do not overcharge or puncture the battery.
- Secure the battery firmly to prevent shifting during use.

Emergency Stop Procedure

- Press the “Stop All” button on the UI to immediately stop all motors and servos.
- Alternatively, use the hardware power switch to cut off power to the entire system.

Environmental Use

- This machine is not weatherproof. Do not operate in rain or high humidity.
- For outdoor use, ensure electronics are shielded and the surface is dry.

B.7.2 Operating Instructions

1. Power On the System
- Connect the battery.
- Flip the hardware power switch to “ON”.
- Wait for the Raspberry Pi and UI to fully boot.

2. Configure Settings on the Touchscreen UI
- Adjust Motor 1 and Motor 2 sliders to control topspin and backspin.
- Set Servo 1 (feed speed) to Slow, Fast, or Off.
- Use Servo 2 controls to rotate the launch angle left or right.
- Set a launch delay (optional) to allow time to move into position.
- Press “Start” to begin the launch sequence.
3. Stop Operation
- Press “Stop” to halt all motors and servos immediately.
- Power off the system after use to preserve battery life.

B.7.3 Maintenance and Storage Tips

- After each use, inspect moving parts for debris or damage.
- Recharge the battery after each session.
- Store the machine in a dry, temperature-controlled environment.
- Periodically check printed parts for wear or cracks, especially gears and servo mounts.

B.8 Troubleshooting Guide

This guide outlines common issues users may encounter while assembling or operating the pickleball throwing machine, along with suggested solutions.

Issue 1: UI Does Not Launch on Startup

Possible Causes:

- .desktop file is not executable
- Incorrect file path in .desktop configuration
- Missing Python libraries (e.g., Kivy)

Solutions:

- Run the following command to make the file executable:

### chmod +x /home/pi/Desktop/PickleballApp.desktop

- Double-check that the Exec line points to the correct path for UI.py
- Manually launch the app to test it:

### python3 /home/pi/UI.py

- Reinstall libraries with:

### pip3 install kivy --break-system-packages

Issue 2: I2C Devices Not Detected (No Response from PCA9685)

Possible Causes:

- SDA/SCL wiring is incorrect
- I2C interface is not enabled
- 3.3V or GND is not connected

Solutions:

- Check wiring:
SDA → GPIO 2 (Pin 3)
SCL → GPIO 3 (Pin 5)
- Confirm that I2C is enabled via sudo raspi-config
- Run i2cdetect -y 1 to scan for devices. You should see an address like 0x40 for

PCA9685

- If no address appears, double-check voltage and ground connections

Issue 3: Motors Not Spinning

Possible Causes:

- Incorrect GPIO wiring

- Motor drivers not receiving power
- Python script not sending signals properly

Solutions:

- Confirm motor driver connections to GPIO pins as per your circuit diagram
- Use a multimeter to check voltage across motor terminals
- Test basic motor control via Python to isolate software/hardware:
- import RPi.GPIO as GPIO

GPIO.setmode(GPIO.BCM)

GPIO.setup(20, GPIO.OUT)

GPIO.output(20, GPIO.HIGH)

Issue 4: Servos Not Responding or Spinning Constantly

Possible Causes:

- PWM signal not reaching servo
- Incorrect I2C address or driver issue
- Servo control code not functioning

Solutions:

- Verify I2C connection and PCA9685 wiring
- Try Adafruit’s ServoKit test example to isolate servo response
- Double-check | servo | channel | indexing | in | your | code | (e.g.,

### kit.continuous_servo[0])

Issue 5: Raspberry Pi Crashes or Freezes

Possible Causes:

- Underpowered system
- Voltage drop from motors or screen
- Overloaded CPU

Solutions:

- Ensure Raspberry Pi is powered through a regulated 5V line using the LM2596 step-down converter
- Power the Pi separately from high-draw components like motors
- Avoid running background processes that consume CPU resources

General Tips:

- Always reboot after enabling new interfaces or modifying config files
- Use short, clean wiring and proper connectors to minimize noise and voltage drops
- Label wires to make troubleshooting easier
- Search online forums (e.g., Raspberry Pi Stack Exchange) for issues related to specific libraries or hardware setups

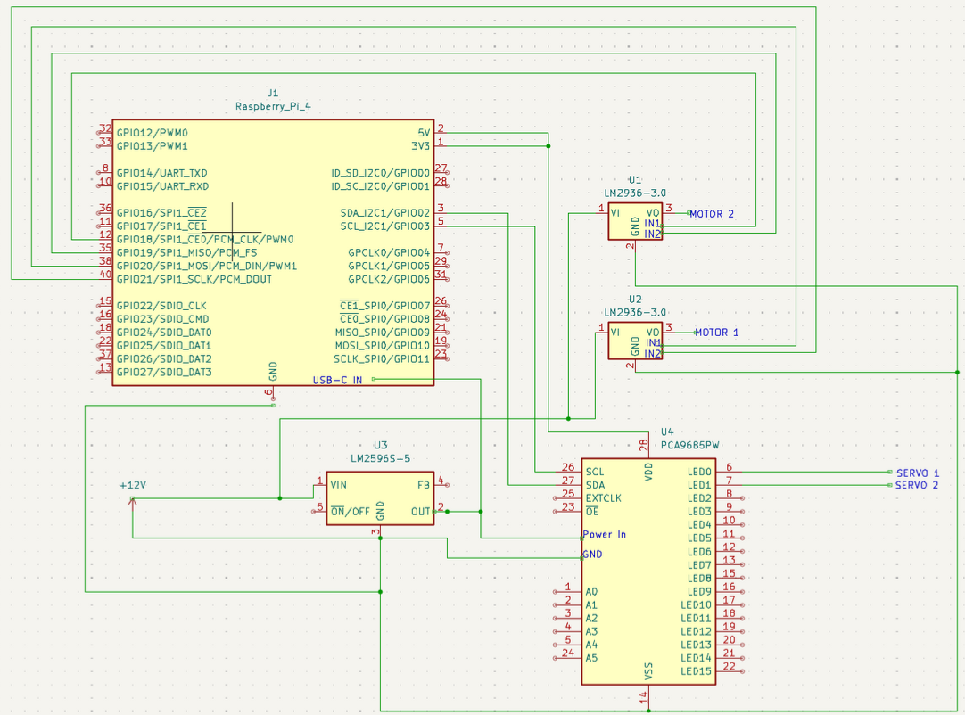
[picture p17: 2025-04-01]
docs/Instructions/Wiring_diagram.png

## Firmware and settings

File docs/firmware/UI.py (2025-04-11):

#!/usr/bin/env python3
from kivy.app import App
from kivy.uix.boxlayout import BoxLayout
from kivy.uix.slider import Slider
from kivy.uix.button import Button
from kivy.uix.label import Label
from kivy.uix.spinner import Spinner
from kivy.clock import Clock

import RPi.GPIO as GPIO
from adafruit_servokit import ServoKit
import time

# --- Hardware Setup ---

# Set up GPIO for motors (using IBT-4 controllers)
GPIO.setmode(GPIO.BCM)
# Motor 1 on GPIO 18 & 19; Motor 2 on GPIO 20 & 21
MOTOR1_IN1 = 18
MOTOR1_IN2 = 19
MOTOR2_IN1 = 20
MOTOR2_IN2 = 21

GPIO.setup(MOTOR1_IN1, GPIO.OUT)
GPIO.setup(MOTOR1_IN2, GPIO.OUT)
GPIO.setup(MOTOR2_IN1, GPIO.OUT)
GPIO.setup(MOTOR2_IN2, GPIO.OUT)

# For speed control, we assume PWM is applied on the IN1 pin.
MOTOR1_PWM = GPIO.PWM(MOTOR1_IN1, 1000)  # 1 kHz frequency
MOTOR2_PWM = GPIO.PWM(MOTOR2_IN1, 1000)
MOTOR1_PWM.start(0)
MOTOR2_PWM.start(0)

# Set up ServoKit for servos (assume channel 0 for servo 1, channel 1 for servo 2)
kit = ServoKit(channels=16)

# --- Hardware Control Functions ---

def set_motor_speed(motor, speed):
    """
    Controls IBT-4 motor speed (0-100).
    For Motor 1: uses MOTOR1_IN1 (PWM) and MOTOR1_IN2 for direction.
    For Motor 2: uses MOTOR2_IN1 (PWM) and MOTOR2_IN2.
    Here we assume only forward motion; adjust as needed.
    """
    if motor == 1:
        GPIO.output(MOTOR1_IN2, GPIO.LOW)
        MOTOR1_PWM.ChangeDutyCycle(speed)
        print(f"Motor 1 set to speed {speed}")
    elif motor == 2:
        GPIO.output(MOTOR2_IN2, GPIO.LOW)
        MOTOR2_PWM.ChangeDutyCycle(speed)
        print(f"Motor 2 set to speed {speed}")
    else:
        print("Invalid motor selection")

def set_servo1_mode(mode_value):
    """
    Controls Servo 1 on channel 0.
    mode_value should be: 60 (Fast), 85 (Medium), 105 (Slow), 115 (Very Slow), or 125 (Off).
    Moves the servo, waits a bit, but does NOT detach (angle=None) anymore.
    """
    print(f"Setting Servo 1 to {mode_value}")
    kit.servo[0].angle = mode_value
    time.sleep(0.5)
    print("Servo 1 position set.")

def set_servo2_action(action):
    """
    Controls Servo 2 on channel 1.
    action: 'left' -> 72, 'right' -> 180.
    Moves the servo, waits, then detaches.
    """
    if action == 'left':
        value = 72
    elif action == 'right':
        value = 180
    else:
        print("Invalid action for Servo 2")
        return
    print(f"Setting Servo 2 to {value} for action {action}")
    kit.servo[1].angle = value
    time.sleep(0.5)
    kit.servo[1].angle = None
    print("Servo 2 detached.")

def stop_all():
    """Stop both motors and set Servo 1 to off (125)."""
    set_motor_speed(1, 0)
    set_motor_speed(2, 0)
    set_servo1_mode(125)   # Value may require modification depending on the servo. 
    print("Stop all command executed.")

# --- Kivy UI ---

class ControlPanel(BoxLayout):
    def __init__(self, **kwargs):
        super().__init__(**kwargs)
        self.orientation = 'vertical'
        self.padding = 20
        self.spacing = 20

        # Title Label
        self.add_widget(Label(text="Pickleball Control Panel", font_size=35))

        # Motor 1 slider and label
        self.motor1_value = 0
        self.motor1_label = Label(text="Topspin: 0", font_size=30)
        self.motor1_slider = Slider(min=0, max=100, value=0)
        self.motor1_slider.bind(value=self.on_motor1_change)
        self.add_widget(self.motor1_label)
        self.add_widget(self.motor1_slider)

        # Motor 2 slider and label
        self.motor2_value = 0
        self.motor2_label = Label(text="Backspin: 0", font_size=30)
        self.motor2_slider = Slider(min=0, max=100, value=0)
        self.motor2_slider.bind(value=self.on_motor2_change)
        self.add_widget(self.motor2_label)
        self.add_widget(self.motor2_slider)

        # Servo 1 control (Spinner)
        self.add_widget(Label(text="Feed Speed", font_size=30))
        self.servo1_selection = "Off"  # default
        self.servo1_spinner = Spinner(
            text="Off",
            values=("Fast", "Medium", "Slow", "Very Slow", "Off"),
            size_hint=(None, None),
            size=(200, 44),
	    font_size='30sp'
        )
        self.servo1_spinner.bind(text=self.on_servo1_change)
        self.add_widget(self.servo1_spinner)

        # Servo 2 control (Buttons)
        self.add_widget(Label(text="Launch Angle", font_size=30))
        btn_layout = BoxLayout(orientation='horizontal', spacing=20, size_hint=(1, None), height=50)
        self.btn_left = Button(text="Rotate Left", font_size='30sp')
        self.btn_left.bind(on_release=lambda instance: set_servo2_action('left'))
        self.btn_right = Button(text="Rotate Right", font_size='30sp')
        self.btn_right.bind(on_release=lambda instance: set_servo2_action('right'))
        btn_layout.add_widget(self.btn_left)
        btn_layout.add_widget(self.btn_right)
        self.add_widget(btn_layout)

        # Delay selection (Spinner) for motor start
        self.add_widget(Label(text="Delay before start (seconds):", font_size=30))
        self.delay_spinner = Spinner(
            text="0",
            values=("0", "5", "10"),
            size_hint=(None, None),
            size=(200, 44),
	    font_size='30sp'
        )
        self.add_widget(self.delay_spinner)

        # Start button to initiate the system
        self.start_button = Button(text="Start", size_hint=(1, None), height=50, font_size='30sp')
        self.start_button.bind(on_release=self.start_system)
        self.add_widget(self.start_button)

        # Stop All button
        self.stop_button = Button(text="Stop All", size_hint=(1, None), height=50, font_size='30sp')
        self.stop_button.bind(on_release=lambda instance: stop_all())
        self.add_widget(self.stop_button)

    def on_motor1_change(self, instance, value):
        self.motor1_value = int(value)
        self.motor1_label.text = f"Topspin: {int(value)}"

    def on_motor2_change(self, instance, value):
        self.motor2_value = int(value)
        self.motor2_label.text = f"Backspin: {int(value)}"

    def on_servo1_change(self, spinner, text):
        self.servo1_selection = text

    def start_system(self, instance):
        try:
            delay = float(self.delay_spinner.text)
        except ValueError:
            delay = 0
        print(f"Starting system in {delay} seconds...")
        # Schedule the system initiation after the specified delay
        Clock.schedule_once(lambda dt: self.initiate_system(), delay)

    def initiate_system(self):
        # Apply the stored motor values
        set_motor_speed(1, self.motor1_value)
        set_motor_speed(2, self.motor2_value)
        # Map the servo1 selection to the proper value: Fast=60, Medium=85, Slow=105, VerySlow=115, Off=125  (may require modification depending on the servo)
        mapping = {"Fast": 60, "Medium": 85, "Slow": 105, "Very Slow": 115, "Off": 125}  
        mode_value = mapping.get(self.servo1_selection, 130)
        set_servo1_mode(mode_value)
        print("System initiated.")

class PickleballApp(App):
    def build(self):
        return ControlPanel()

if __name__ == '__main__':
    PickleballApp().run()
